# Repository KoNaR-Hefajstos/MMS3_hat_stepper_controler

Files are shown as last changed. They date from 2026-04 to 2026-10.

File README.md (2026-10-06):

# Hat Sterownik silnika krokowego TMC5130A z przetwornicą Buck

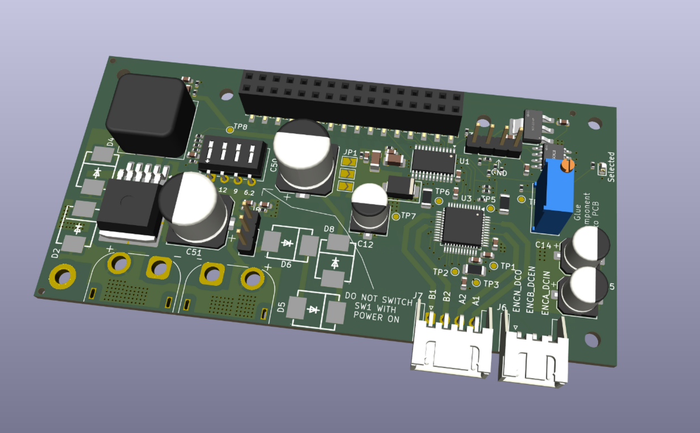
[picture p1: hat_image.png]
zdjecie hata


## Sekcja 1: Dokumentacja Hat'a

### Krótki opis hat'a
Projekt to sterownik silnika krokowego, oparty na dedykowanym układzie scalonym **TMC5130A-TA** sterowanym po SPI. Urządzenie pozwala na sterowanie silnikami o prądzie cewki do 2A (maksymalnie 2.5A w piku). Dodadkowo na PCB jest przetwornica buck oraz złącza i przełączniki do wybierania zasilania, między VIN, 6.2V, 9V, 12V, 24V.

### Zgodność ze standardem ChainBus

* ✅  Używa złącza ChainBus, nie zmienia jego miejsca ani pinoutu.
* ✅  Używa wyłącznie interfejsów I2C, SPI lub UART i nie inicjuje samodzielnie nowych transmisji (Nie jest master'em I2C albo SPI).
* ✅  Spełnia wymagania mechaniczne standardu (wymiary PCB, rozstaw otworów).
* ✅  Pobiera maksymalny prąd zgodny z ilością na jednego hat'a
* ✅  Obsługuje napięcie wejściowe BRD_VIN do wartości 48V.
### Komunikacja i adresowanie

#### Magistrala SPI

| Układ (IC) | Funkcja | Połączenie CS |
| :--- | :--- | :--- |
| **TMC5130A** | Sterownik silnika krokowego | Bezpośrednio do Chainbus'a |

---

### Pinout złączy

#### J6 — Złącze enkodera
Złącze przeznaczone do podłączenia zewnętrznego enkodera zwrotnego.

| Pin | Sygnał | Opis |
| :---- | :--- | :--- |
| **1** | `ENCN_DCO` | |
| **2** | `ENCB_DCEN_CFG4` | |
| **3** | `ENCA_DCIN_CFG5` | |

#### J7 — Złącze silnika krokowego
Złącze wyjściowe do podłączenia faz silnika dwufazowego.

| Pin | Sygnał | Opis |
| :---- | :----- | :--- |
| **1** | `B1` | Faza B (wyjście 1) |
| **2** | `B2` | Faza B (wyjście 2) |
| **3** | `A2` | Faza A (wyjście 2) |
| **4** | `A1` | Faza A (wyjście 1) |

---

### Konfiguracja układu (Zworki/Przełączniki)

#### J8 — Wybór źródła zasilania stopnia mocy silnika
Zworka J8 służy do określenia, skąd sterownik TMC5130A pobiera napięcie zasilania cewek:

| Pozycja zworki  | Wybrane źródło zasilania | Opis |
| :--- | :--- | :--- |
| **Pozycja 1-2** | Przetwornica Buck | Zasilanie silnika z wewnętrznej przetwornicy obniżającej napięcie (napięcie regulowane przełącznikiem SW1). |
| **Pozycja 2-3** | Złącze XT60 (VIN) | Bezpośrednie zasilanie ze złącza XT60. Tor ten posiada trzy szeregowe diody (D5, D6, D7) w celu bezpiecznego dopasowania do maksymalnego zakresu napięć standardu ChainBus. |

#### SW1 — Wybór napięcia wyjściowego przetwornicy Buck
Przełącznik pozwala na wybór napięcia zasilania silnika, jeśli zworka J8 jest ustawiona na zasilanie z przetwornicy.

| Aktywny kanał SW1 | Wyjściowe napięcie | Uwagi |
| :--- | :--- | :--- |
| **Pozycja 1** | 24 V | Domyślne napięcie dla standardowych silników |
| **Pozycja 2** | 12 V | Dla silników średniego napięcia |
| **Pozycja 3** | 9 V | Napięcie zredukowane |
| **Pozycja 4** | 6.2 V | Minimalne stabilne napięcie pracy układu |

* **⚠️ WAŻNE:** Zmianę położenia przełącznika SW1 należy wykonywać wyłącznie przy całkowicie odłączonym zasilaniu modułu. W danym momencie może być włączony tylko jeden przełącznik wyboru napięcia.
* **Modyfikacja poziomów napięć:** Istnieje możliwość zmiany napięc wyjściowych przetwornicy przez zmiane **R14**, **R15** lub **R16**.

#### RV1 — Trymer regulacyjny prądu referencyjnego (AIN_REF)
Potencjometr montażowy RV1 służy do analogowego ustawienia napięcia odniesienia na pinie `AIN_REF` układu TMC5130A, co pozwala na ręczne ograniczenie maksymalnego prądu płynącego przez cewki silnika krokowego.

---

### Szczegółowy opis techniczny
Hat sterownika silnika krokowego używawający TMC5130A-TA. I = 2A

TMC5130A jest sterowana po SPI co umożliwia pełną, programową kontrolę nad wszystkimi parametrami ruchu. Umożliwia to precyzyjną regulację prędkości i pozycji, automatyczne generowanie ramp przyspieszeń i hamowań (co odciąża główny mikrokontroler od obliczeń w czasie rzeczywistym), a także bieżący odczyt diagnostyczny stanu pracy stopnia mocy oraz bezczujnikowe wykrywanie przeciążeń i zablokowania osi.

Opóźniania spowodowane użyciem SPI zamiast standardowego driver'a stepper'a (STEP DIR) poniżej 100us (przesłanie jedner ramki ~= 10us) oraz powoduje mniejsze zajęcie mikrokontrolera (rząda tylko efektu, nie generuje impulsów STEP/DIR)

Przetwornica buck została zaprojektowana tak, aby konwertować napięcie wejściowe na wybrane niższe napięcia robocze silnika. Zaleca się stosowanie zewnętrznego zasilania doprowadzonego do złącza XT60.

### Gotowe arkusze hierarchiczne
W strukturze projektu wykorzystano następujące arkusze hierarchiczne:
* **Buck Regulator** – Układ impulsowej przetwornicy obniżającej napięcie LM2596, wyposażony w przełącznik sprzężenia zwrotnego (SW1) umożliwiający zmianę napięcia wyjściowego (6.2V, 9V, 12V, 24V).
* **Stepper controller** – Schemat  sterownika silnika krokowego TMC5130A-T

---

## Sekcja 2: Specyfikacja standardu ChainBus

### Architektura i łączenie modułów
Standard ChainBus umożliwia modułowe łączenie hatów. Na jednym MMS3 można zamontować pionowo **do 8 hat'ów**. Połączenie realizowane jest poprzez wpięcie złącza męskiego kolejnego hat'a w złącze żeńskie poprzedniego.

### Komunikacja i sterowanie
Magistrala ChainBus jest w pełni cyfrowa. Płyta główna nie steruje bezpośrednio sygnałami ogólnego przeznaczenia (GPIO) na poszczególnych hat'ach. Wszelkie operacje muszą być realizowane przez dedykowane układy scalone komunikujące się przez interfejsy systemowe.

Wybór aktywnego modułu realizowany jest przez układ przełącznika magistrali (bus switch) na płycie głównej. Dzięki temu linie I2C, SPI i UART są niezależne dla każdego hat'a (brak konfliktów adresów I2C oraz kolizji na liniach SPI CS).
* **Identyfikacja:** Każdy moduł powinien posiadać pamięć EEPROM na magistrali I2C w celu identyfikacji płyty przez system - układ M24C64-W skonfigurowany na adres `1010000` przy liniach adresowych A0, A1, A2 zwartych do masy.

### Zasilanie
Złącze ChainBus dostarcza następujące linie zasilania:

| Magistrala zasilania | Napięcie znamionowe | Maksymalny prąd (łączny dla 8 hatów) | Szacowany prąd na jeden hat |
| :--- | :---: | :---: | :---: |
| **5V** | 5.0 V | 1.0 A | 125 mA |
| **12V stby** | 12.0 V | 0.5 A | 65 mA |
| **BRD_VIN** | 12.0 V – 48.0 V | 1.5 A | 185 mA |

*   Komponenty podłączone do linii `BRD_VIN` muszą być przystosowane do pracy z napięciem od 12V do **48 V**.
*   W przypadku dużego zapotrzebowania na prąd (np. jednoczesna praca kilku silników o wysokim momencie obrotowym), dopuszczalne jest skorzystanie z dedykowanego wysokoprądowego złącza XT60.

### Wymagania mechaniczne i złącza
* **Wymiary PCB:** Niedozwolona jest zmiana obrysu płytki oraz położenia otworów montażowych, aby zachować kompatybilność mechaniczną.
* **Pozycjonowanie złączy ChainBus:** Położenie złącza standardu 2x16 SMD (raster 2.54 mm) musi być zgodne z szablonem. Złącze żeńskie montowane jest na stronie FRONT, natomiast złącze męskie na stronie BACK.
* **Komponenty:** Wszystkie komponenty powinny znajdować się na stronie FRONT płytki, aby uniknąć kolizji mechanicznych z elementami sąsiadujących modułów w stosie.

---

## Sekcja 3: Licencja, linki i tagi

### Licencjonowanie projektu

*   **PCB:** [CERN-OHL-W](https://ohwr.org/project/cernohl/wikis/Documents/CERN-OHL-version-2) - Umożliwia modyfikacje i sprzedaż, ale wymaga zachowania informacji o autorze, a wszelkie pochodne projekty muszą być udostępnione jako open source.
*   **Software:** [MIT License](https://opensource.org/licenses/MIT) - Umożliwia dowolne modyfikacje i sprzedaż komercyjną pod warunkiem dołączenia informacji o autorze (kod wynikowy nie musi być udostępniany jako open source).

### Tagi projektu
#chainbus #MMS3 #ModuCard #StepperDriver #TMC5130A #BuckConverter

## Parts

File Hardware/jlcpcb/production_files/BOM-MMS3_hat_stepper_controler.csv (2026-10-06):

Comment | Designator | Footprint | LCSC | Quantity
0603/3R3 | R4 | R_1206 | C911994 | 1
100kΩ | R5 | R_0402 | C25741 | 1
100nF | C1,C2,C20,C21,C23,C24,C3,C7,C8,C9 | C_0603 | C14663 | 10
100uF | C50,C51 | CP_Elec_10x10 | C249838 | 2
100uH 4A | L1 | L_Sunlord_SWRB1207S | C5368704 | 1
10kΩ | R1,R19,R2,R20,R21,R22,R23,R24,R25 | R_0402 | C25744 | 9
10uF | C16,C18 | C_0603 | C19702 | 2
1206, 0R15, 0.5W | R6,R7 | R_1206 | C2683383 | 2
18.7k | R13 | R_0402 | C11476 | 1
1kΩ | R12 | R_0402 | C11702 | 1
22nF | C5 | C_0603 | C21122 | 1
3.3nF | C22 | C_0603 | C1613 | 1
330Ω | R26 | R_0402 | C25104 | 1
33kΩ | R10,R11,R17,R18,R8,R9 | R_0402 | C25779 | 6
4.7uF | C4 | C_0603 | C19666 | 1
4.7uF | C10,C11 | C_1206 | C29823 | 2
470nF | C6 | C_0603 | C1623 | 1
47u | C12,C14,C15 | CP_Elec_6.3x7.7 | C7461235 | 3
5.11k | R16 | R_0402 | C274895 | 1
9.53k | R15 | R_0402 | C295883 | 1
AMS1117 | U4 | SOT-223-3_L6.5-W3.4-P2.30-LS7.0-BR | C6186 | 1
LM2596HVS-ADJRG | U5 | TO-263-5_TabPin3 | C22439312 | 1
M24C64 | U2 | SOIC-8_L5.0-W4.0-P1.27-LS6.0-BL | C79988 | 1
Red | D7 | D_0603 | C2286 | 1
SN74CB3Q3384APW | U1 | TSSOP-24_4.4x7.8mm_P0.65mm | C469874 | 1
SS510C | D2,D4,D5,D6,D8 | SMC_L7.1-W6.2-LS8.1-RD | C123944 | 5
SW_DIP_x04 | SW1 | SW_DIP_SPSTx04_Slide_6.7x11.72mm_W7.62mm_P2.54mm_LowProfile | C231756 | 1
TMC5130A-TA | U3 | TQFP-48-1EP_7x7mm_P0.5mm_EP5x5mm_ThermalVias | C188832 | 1
TestPoint | TP4 | TestPoint_Pad_D1.0mm |  | 1
TestPoint | TP1 | TestPoint_Pad_D1.0mm |  | 1
16.5k | R14 | R_0402 |  | 1
TestPoint | TP7 | TestPoint_Pad_D1.0mm |  | 1
TestPoint | TP6 | TestPoint_Pad_D1.0mm |  | 1
TestPoint | TP8 | TestPoint_Pad_D1.0mm |  | 1
TestPoint | TP5 | TestPoint_Pad_D1.0mm |  | 1
100K TRIM | RV1 | Potentiometer_Bourns_3296W_Vertical |  | 1
TestPoint | TP2 | TestPoint_Pad_D1.0mm |  | 1
TestPoint | TP3 | TestPoint_Pad_D1.0mm |  | 1

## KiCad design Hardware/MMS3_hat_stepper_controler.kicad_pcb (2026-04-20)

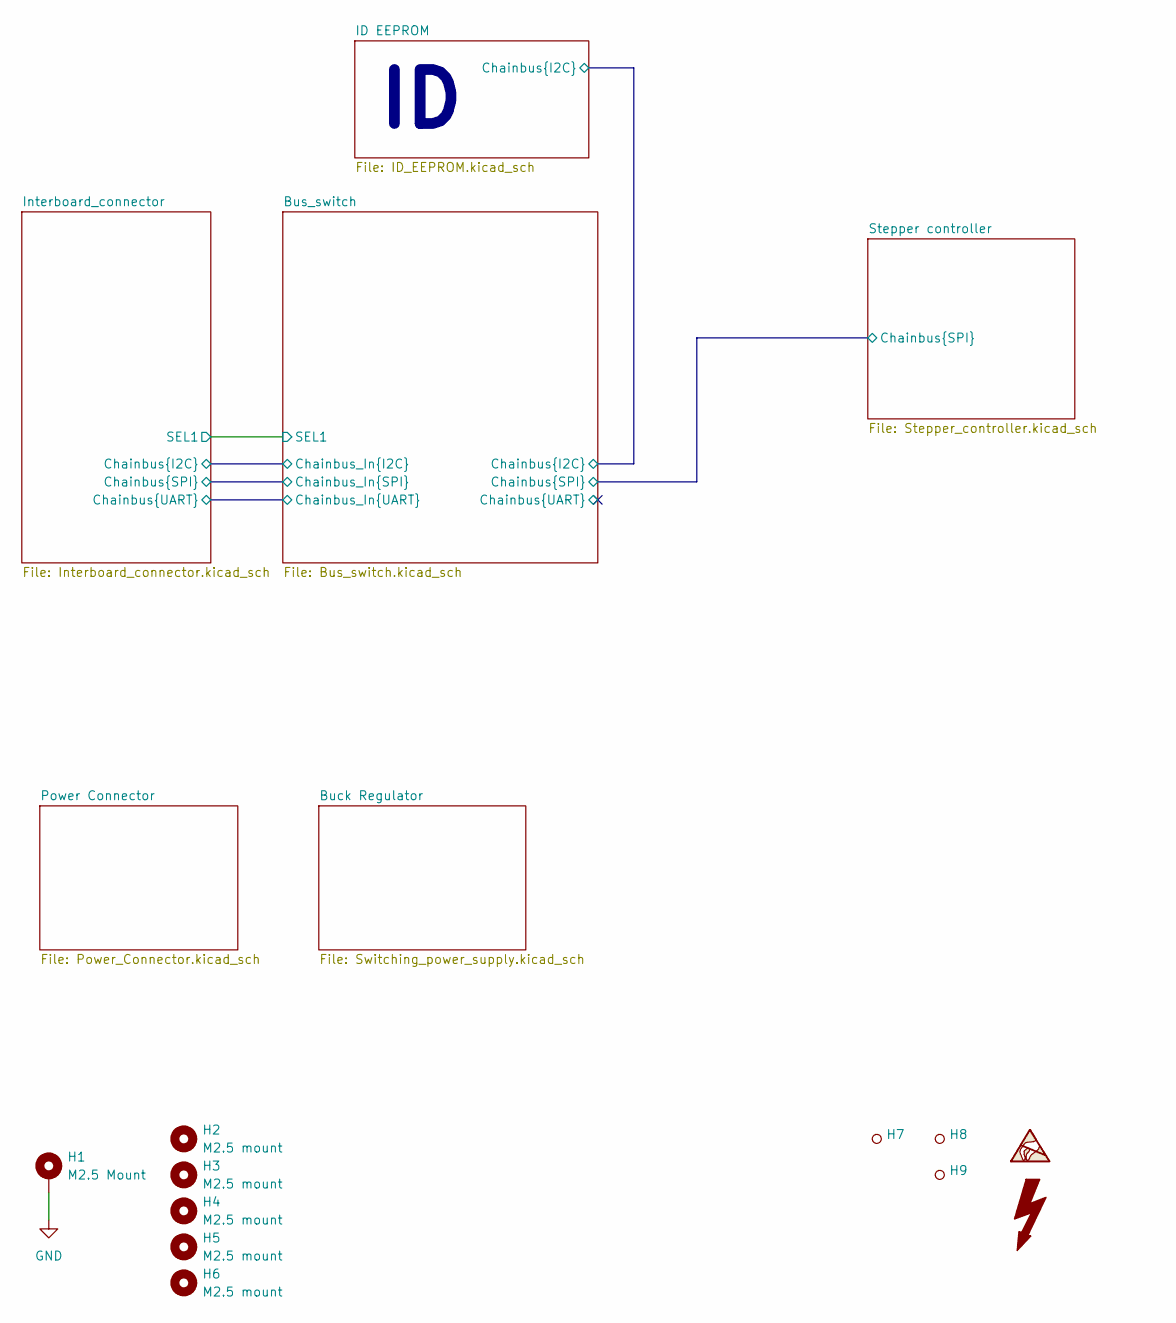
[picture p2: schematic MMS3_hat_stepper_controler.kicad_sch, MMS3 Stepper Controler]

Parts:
H1: M2.5 Mount; MountingHole_2.7mm_M2.5_DIN965_Pad_TopOnly
H2, H3, H4, H5, H6: M2.5 mount; MountingHole_2.7mm_M2.5
H7, H8, H9: Hole_Tooling_JLCPCB

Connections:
GND: H1.1 (1_1); also elsewhere on the board

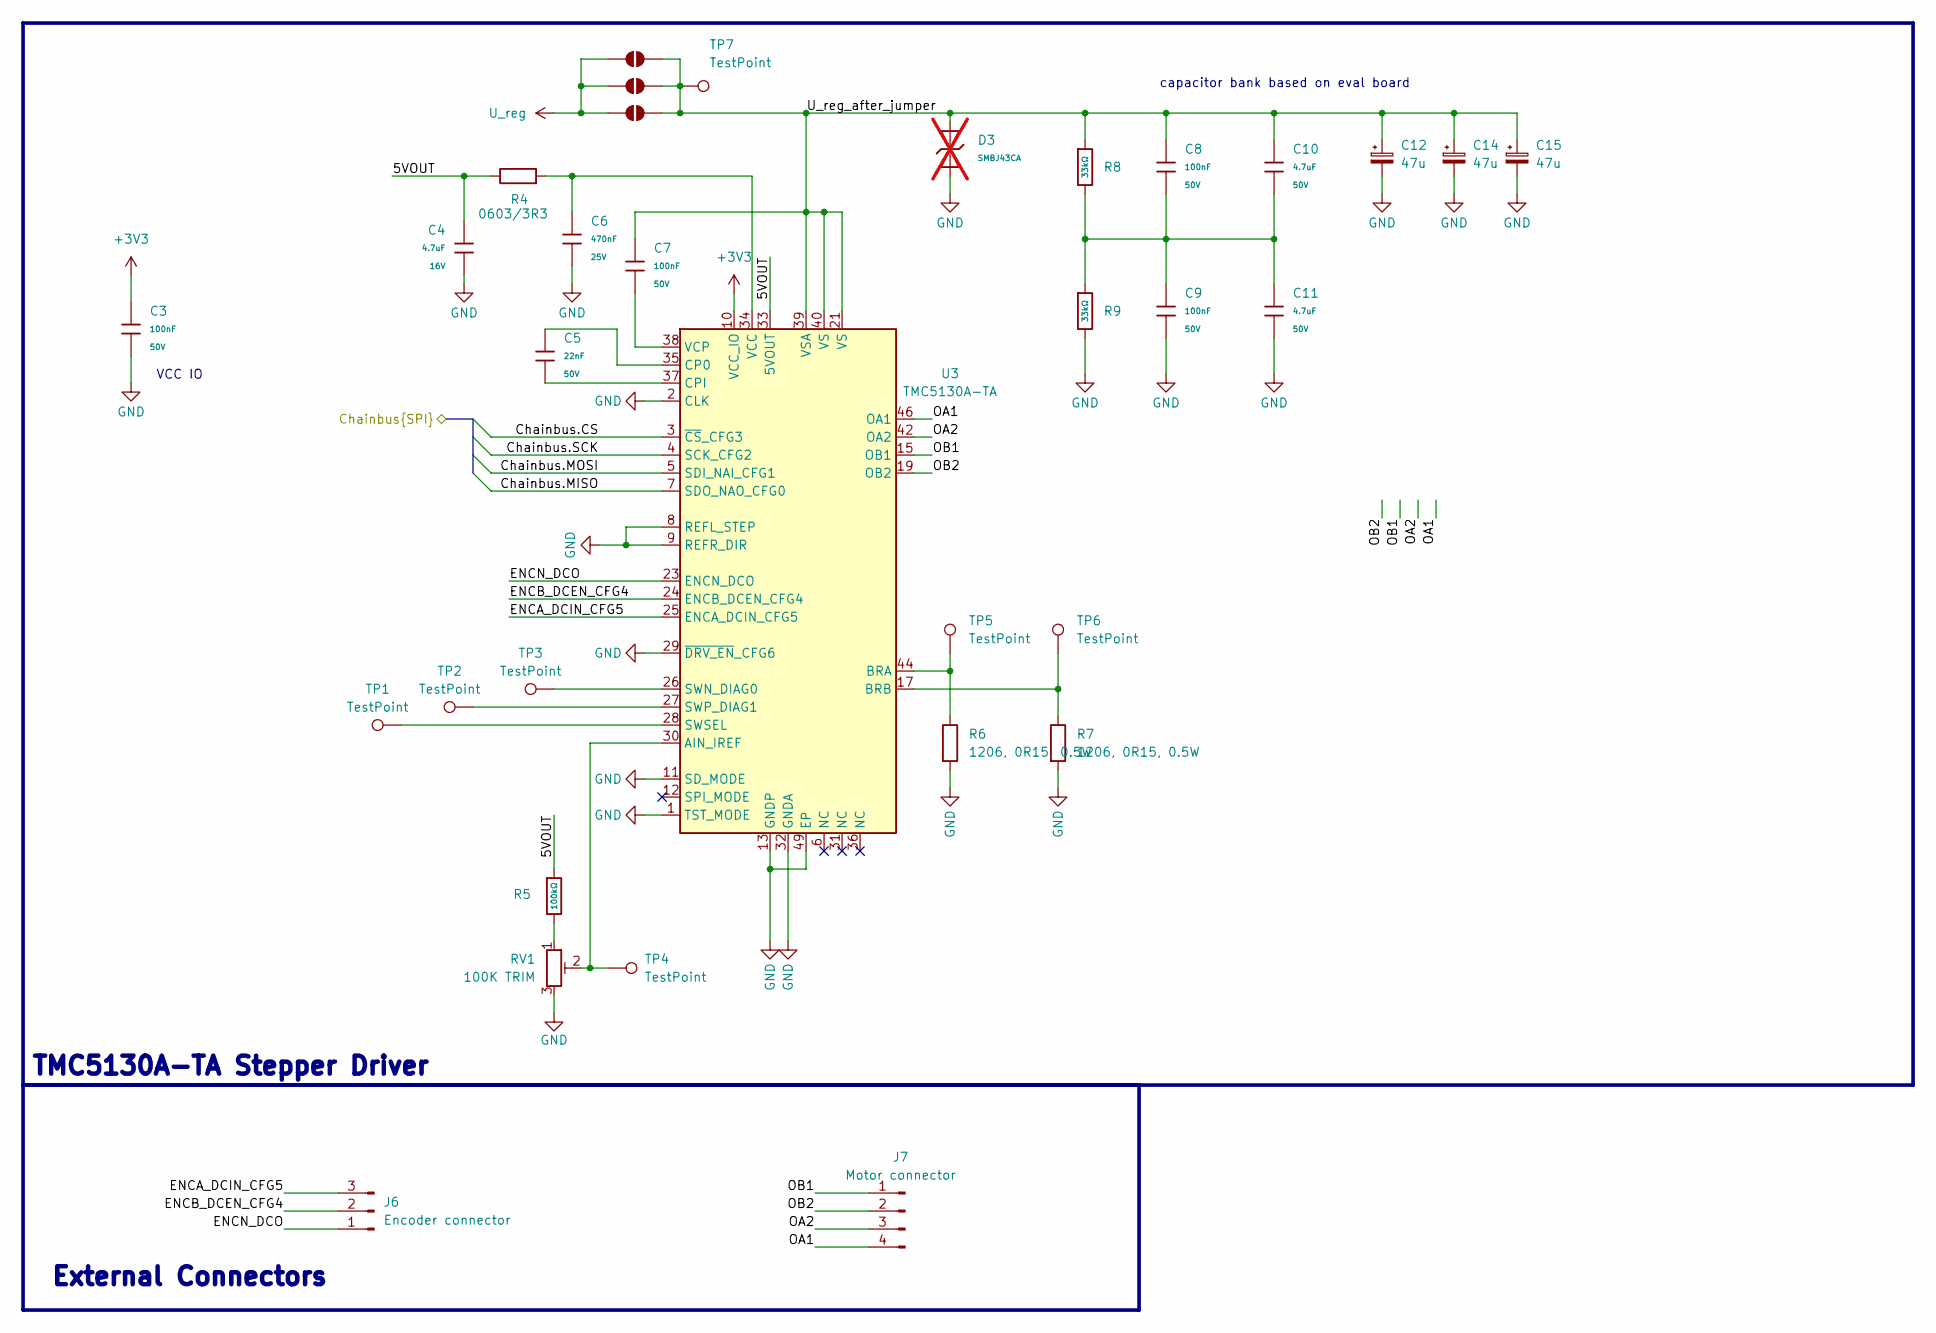
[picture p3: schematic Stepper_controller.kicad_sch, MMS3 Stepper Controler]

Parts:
C3, C7, C8, C9: 100nF; C_0603; Voltage Rated 50V; Tolerance ±10%; Part CC0603KRX7R9BB104; LCSC C14663
C4: 4.7uF; C_0603; Voltage Rated 16V; Tolerance ±10%; Part CL10A475KO8NNNC; LCSC C19666
C5: 22nF; C_0603; Voltage Rated 50V; Tolerance ±10%; Part CL10B223KB8NNNC; LCSC C21122
C6: 470nF; C_0603; Voltage Rated 25V; Tolerance ±10%; Part CL10B474KA8NNNC; LCSC C1623
C10, C11: 4.7uF; C_1206; Voltage Rated 50V; Tolerance ±10%; Part 1206B475K500NT; LCSC C29823
C12, C14, C15: 47u; CP_Elec_6.3x7.7; LCSC C7461235
D3: SMBJ43CA; D_SMB; Breakdown Voltage 52.8V; Part SMBJ43CA; LCSC C41376098; not fitted
J6: Encoder connector; JST_XH_S3B-XH-A-1_1x03_P2.50mm_Horizontal
J7: Motor connector; JST_XH_S4B-XH-A_1x04_P2.50mm_Horizontal
JP1, JP2, JP3: SolderJumper_2_Open; SolderJumper-2_P1.3mm_Open_TrianglePad1.0x1.5mm
R4: 0603/3R3; R_1206; LCSC C911994
R5: 100kΩ; R_0402; Overload Voltage (Max) 50V; Tolerance ±1%; Part 0402WGF1003TCE; LCSC C25741
R6, R7: 1206, 0R15, 0.5W; R_1206; LCSC C2683383
R8, R9: 33kΩ; R_0402; Overload Voltage (Max) 50V; Tolerance ±1%; Part 0402WGF3302TCE; LCSC C25779
RV1: 100K TRIM; Potentiometer_Bourns_3296W_Vertical; LCSC C48641782
TP1, TP2, TP3, TP4, TP5, TP6, TP7: TestPoint; TestPoint_Pad_D1.0mm
U3: TMC5130A-TA; TQFP-48-1EP_7x7mm_P0.5mm_EP5x5mm_ThermalVias; LCSC C188832

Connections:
+3V3: C3.1, U3.10 (VCC_IO); also elsewhere on the board
/Bus_switch/Chainbus.CS: U3.3 (~CS_CFG3); also elsewhere on the board
/Bus_switch/Chainbus.MISO: U3.7 (SDO_NAO_CFG0); also elsewhere on the board
/Bus_switch/Chainbus.MOSI: U3.5 (SDI_NAI_CFG1); also elsewhere on the board
/Bus_switch/Chainbus.SCK: U3.4 (SCK_CFG2); also elsewhere on the board
/Stepper controller/5VOUT: C4.1, R4.1, R5.1, U3.33 (5VOUT)
/Stepper controller/ENCA_DCIN_CFG5: J6.3, U3.25 (ENCA_DCIN_CFG5)
/Stepper controller/ENCB_DCEN_CFG4: J6.2, U3.24 (ENCB_DCEN_CFG4)
/Stepper controller/ENCN_DCO: J6.1, U3.23 (ENCN_DCO)
/Stepper controller/OA1: J7.4, U3.46 (OA1)
/Stepper controller/OA2: J7.3, U3.42 (OA2)
/Stepper controller/OB1: J7.1, U3.15 (OB1)
/Stepper controller/OB2: J7.2, U3.19 (OB2)
/Stepper controller/U_reg_after_jumper: C7.1, C8.1, C10.1, C12.1, C14.1, C15.1, D3.2, JP1.2 (B), JP2.2 (B), JP3.2 (B), R8.1, TP7.1 (1_1), U3.21 (VS), U3.39 (VSA), U3.40 (VS)
GND: C3.2, C4.2, C6.2, C9.2, C11.2, C12.2, C14.2, C15.2, D3.1, R6.2, R7.2, R9.2, RV1.3, U3.1 (TST_MODE), U3.2 (CLK), U3.8 (REFL_STEP), U3.9 (REFR_DIR), U3.11 (SD_MODE), U3.13 (GNDP), U3.29 (~DRV_EN_CFG6), U3.32 (GNDA), U3.48 (GNDP), U3.49 (EP); also elsewhere on the board
unnamed: C8.2, C9.1, C10.2, C11.1, R8.2, R9.1
unnamed: R5.2, RV1.1
unnamed: RV1.2, TP4.1 (1_1), U3.30 (AIN_IREF)
unnamed: R6.1, TP5.1 (1_1), U3.44 (BRA)
unnamed: R7.1, TP6.1 (1_1), U3.17 (BRB)
unnamed: C5.1, U3.35 (CP0)
unnamed: C5.2, U3.37 (CPI)
unnamed: TP3.1 (1_1), U3.26 (SWN_DIAG0)
unnamed: TP2.1 (1_1), U3.27 (SWP_DIAG1)
unnamed: TP1.1 (1_1), U3.28 (SWSEL)
unnamed: C6.1, R4.2, U3.34 (VCC)
unnamed: C7.2, U3.38 (VCP)
U_reg: JP1.1 (A), JP2.1 (A), JP3.1 (A); also elsewhere on the board

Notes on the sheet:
VCC IO
TMC5130A-TA Stepper Driver
External Connectors
capacitor bank based on eval board

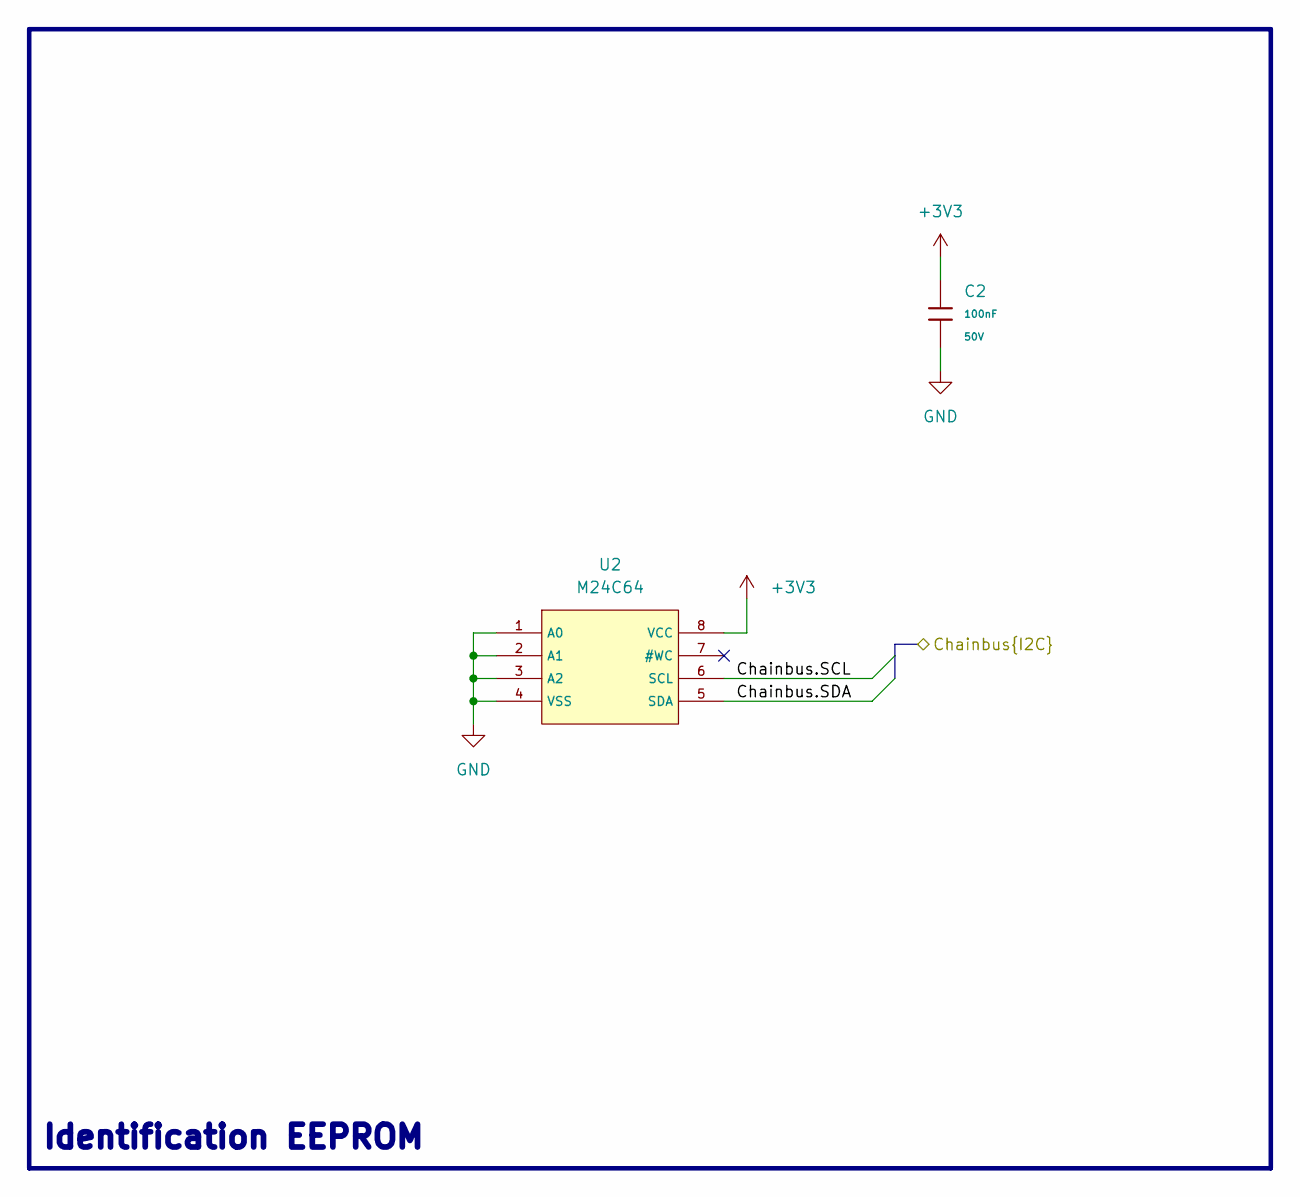
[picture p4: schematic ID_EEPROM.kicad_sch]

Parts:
C2: 100nF; C_0603; Voltage Rated 50V; Tolerance ±10%; Part CC0603KRX7R9BB104; LCSC C14663
U2: M24C64; SOIC-8_L5.0-W4.0-P1.27-LS6.0-BL; Supply Voltage 1.8V~5.5V; Part M24C64-RMN6TP; LCSC C79988

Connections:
+3V3: C2.1, U2.8 (VCC); also elsewhere on the board
/Bus_switch/Chainbus.SCL: U2.6 (SCL); also elsewhere on the board
/Bus_switch/Chainbus.SDA: U2.5 (SDA); also elsewhere on the board
GND: C2.2, U2.1 (A0), U2.2 (A1), U2.3 (A2), U2.4 (VSS); also elsewhere on the board

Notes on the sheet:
Identification EEPROM

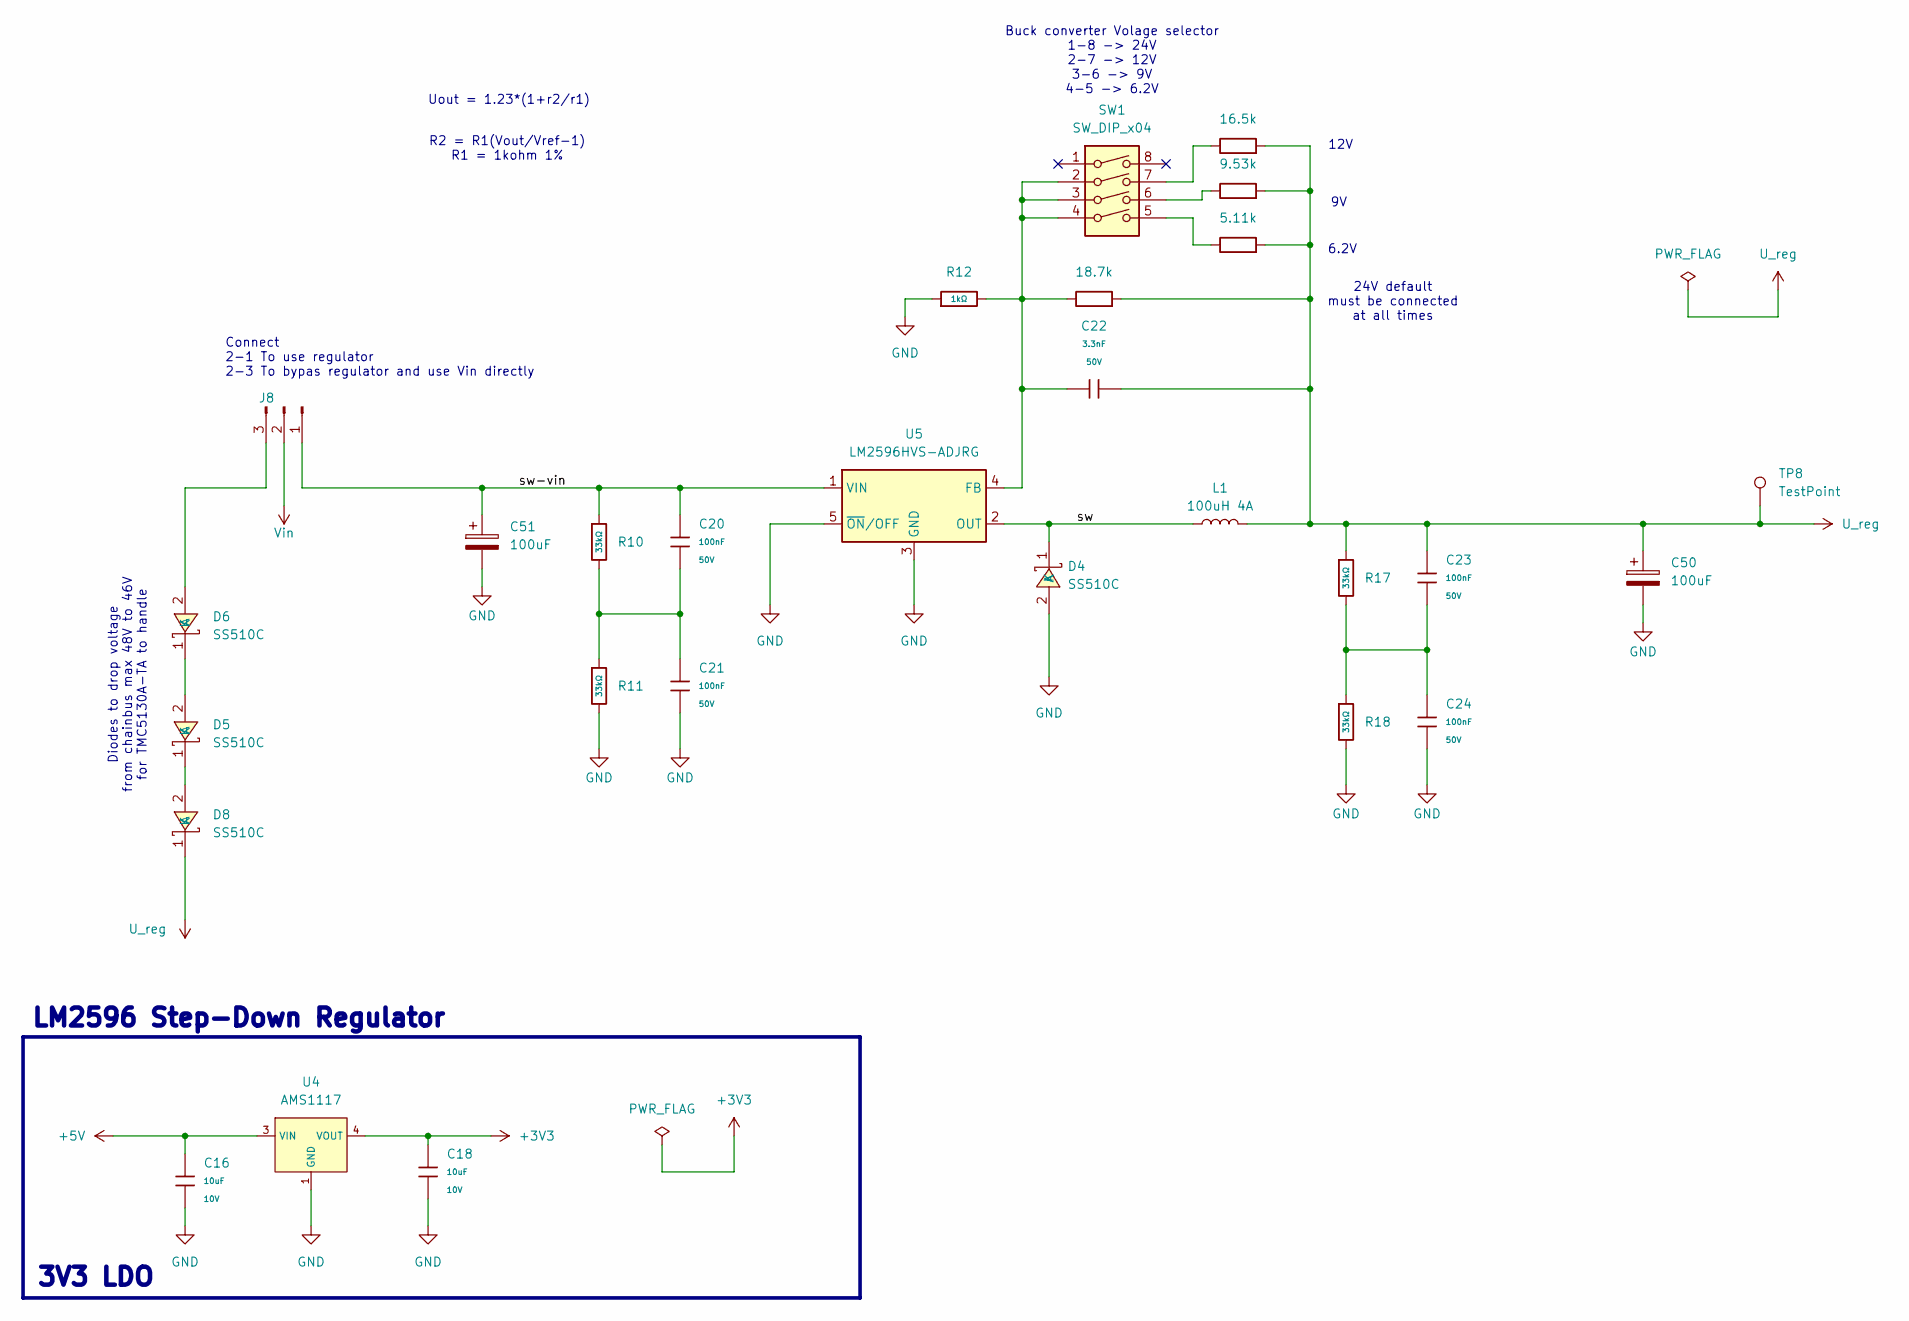
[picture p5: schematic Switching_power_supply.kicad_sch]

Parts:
C16, C18: 10uF; C_0603; Voltage Rated 10V; Tolerance ±10%; Part CL10A106KP8NNNC; LCSC C19702
C20, C21, C23, C24: 100nF; C_0603; Voltage Rated 50V; Tolerance ±10%; Part CC0603KRX7R9BB104; LCSC C14663
C22: 3.3nF; C_0603; Voltage Rated 50V; Tolerance ±10%; Part CL10B332KB8NNNC; LCSC C1613
C50, C51: 100uF; CP_Elec_10x10; MPN VZH101M1KTR-1010; LCSC C249838
D4, D5, D6, D8: SS510C; SMC_L7.1-W6.2-LS8.1-RD; MPN SS510C; LCSC Part C123944
J8: Conn_01x03_Pin; PinHeader_1x03_P2.54mm_Vertical
L1: 100uH 4A; L_Sunlord_SWRB1207S; LCSC C5368704
R10, R11, R17, R18: 33kΩ; R_0402; Overload Voltage (Max) 50V; Tolerance ±1%; Part 0402WGF3302TCE; LCSC C25779
R12: 1kΩ; R_0402; Overload Voltage (Max) 50V; Tolerance ±1%; Part 0402WGF1001TCE; LCSC C11702
R13: 18.7k; R_0402; LCSC C11476
R14: 16.5k; R_0402; LCSC C25857
R15: 9.53k; R_0402; LCSC C295883
R16: 5.11k; R_0402; LCSC C274895
SW1: SW_DIP_x04; SW_DIP_SPSTx04_Slide_6.7x11.72mm_W7.62mm_P2.54mm_LowProfile; LCSC C231756
TP8: TestPoint; TestPoint_Pad_D1.0mm
U4: AMS1117; SOT-223-3_L6.5-W3.4-P2.30-LS7.0-BR; Output Voltage 3.3V; Dropout Voltage 1.3V@(800mA); Part AMS1117-3.3; LCSC C6186
U5: LM2596HVS-ADJRG; TO-263-5_TabPin3; LCSC C22439312

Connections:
+3V3: C18.1, U4.2 (VOUT), U4.4 (VOUT); also elsewhere on the board
+5V: C16.1, U4.3 (VIN); also elsewhere on the board
/Buck Regulator/sw: D4.1 (K), L1.1, U5.2 (OUT)
/Buck Regulator/sw-vin: C20.1, C51.1, J8.1, R10.1, U5.1 (VIN)
GND: C16.2, C18.2, C21.2, C24.2, C50.2, C51.2, D4.2 (A), R11.2, R12.1, R18.2, U4.1 (GND), U5.3 (GND), U5.5 (~ON/OFF); also elsewhere on the board
unnamed: C20.2, C21.1, R10.2, R11.1
unnamed: C23.2, C24.1, R17.2, R18.1
unnamed: D5.2 (A), D6.1 (K)
unnamed: D5.1 (K), D8.2 (A)
unnamed: D6.2 (A), J8.3
unnamed: R14.1, SW1.7
unnamed: R15.1, SW1.6
unnamed: R16.1, SW1.5
unnamed: C22.1, R12.2, R13.1, SW1.2, SW1.3, SW1.4, U5.4 (FB)
U_reg: C22.2, C23.1, C50.1, D8.1 (K), L1.2, R13.2, R14.2, R15.2, R16.2, R17.1, TP8.1 (1_1); also elsewhere on the board
Vin: J8.2; also elsewhere on the board

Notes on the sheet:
6.2V
Diodes to drop voltage from chainbus max 48V to 46V for TMC5130A-TA to handle
3V3 LDO
R2 = R1(Vout/Vref-1) R1 = 1kohm 1%
LM2596 Step-Down Regulator
Uout = 1.23*(1+r2/r1)
Buck converter Volage selector 1-8 -> 24V 2-7 -> 12V 3-6 -> 9V 4-5 -> 6.2V
Connect 2-1 To use regulator 2-3 To bypas regulator and use Vin directly
12V
24V default must be connected at all times

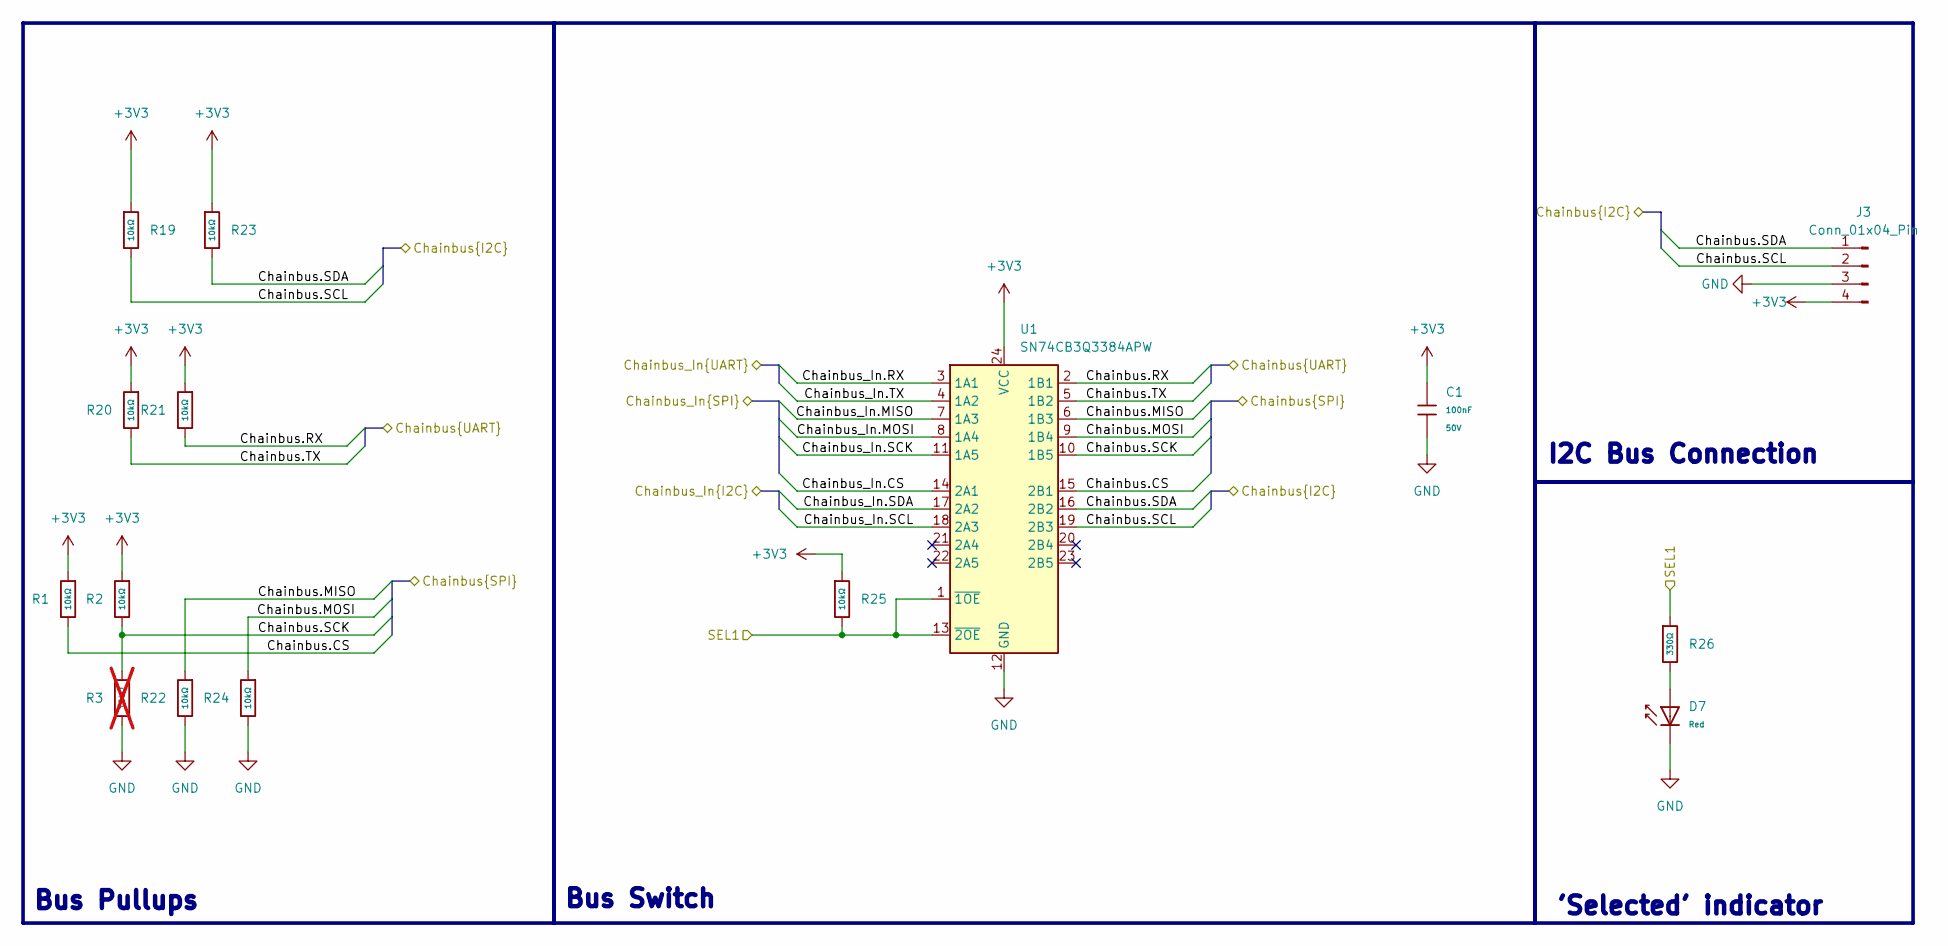
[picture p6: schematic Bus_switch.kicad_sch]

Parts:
C1: 100nF; C_0603; Voltage Rated 50V; Tolerance ±10%; Part CC0603KRX7R9BB104; LCSC C14663
D7: Red; D_0603; Part KT-0603R; LCSC C2286
J3: Conn_01x04_Pin; PinHeader_1x04_P2.54mm_Vertical
R1, R2, R19, R20, R21, R22, R23, R24, R25: 10kΩ; R_0402; Overload Voltage (Max) 50V; Tolerance ±1%; Part 0402WGF1002TCE; LCSC C25744
R3: 10kΩ; R_0402; Overload Voltage (Max) 50V; Tolerance ±1%; Part 0402WGF1002TCE; LCSC C25744; not fitted
R26: 330Ω; R_0402; Overload Voltage (Max) 50V; Tolerance ±1%; Part 0402WGF3300TCE; LCSC C25104
U1: SN74CB3Q3384APW; TSSOP-24_4.4x7.8mm_P0.65mm; LCSC C469874

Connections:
+3V3: C1.1, J3.4, R1.1, R2.1, R19.1, R20.1, R21.1, R23.1, R25.1, U1.24 (VCC); also elsewhere on the board
/Bus_switch/Chainbus.CS: R1.2, U1.15 (2B1); also elsewhere on the board
/Bus_switch/Chainbus.MISO: R22.1, U1.6 (1B3); also elsewhere on the board
/Bus_switch/Chainbus.MOSI: R24.1, U1.9 (1B4); also elsewhere on the board
/Bus_switch/Chainbus.RX: R21.2, U1.2 (1B1)
/Bus_switch/Chainbus.SCK: R2.2, R3.1, U1.10 (1B5); also elsewhere on the board
/Bus_switch/Chainbus.SCL: J3.2, R19.2, U1.19 (2B3); also elsewhere on the board
/Bus_switch/Chainbus.SDA: J3.1, R23.2, U1.16 (2B2); also elsewhere on the board
/Bus_switch/Chainbus.TX: R20.2, U1.5 (1B2)
/Bus_switch/Chainbus_In.CS: U1.14 (2A1); also elsewhere on the board
/Bus_switch/Chainbus_In.MISO: U1.7 (1A3); also elsewhere on the board
/Bus_switch/Chainbus_In.MOSI: U1.8 (1A4); also elsewhere on the board
/Bus_switch/Chainbus_In.RX: U1.3 (1A1); also elsewhere on the board
/Bus_switch/Chainbus_In.SCK: U1.11 (1A5); also elsewhere on the board
/Bus_switch/Chainbus_In.SCL: U1.18 (2A3); also elsewhere on the board
/Bus_switch/Chainbus_In.SDA: U1.17 (2A2); also elsewhere on the board
/Bus_switch/Chainbus_In.TX: U1.4 (1A2); also elsewhere on the board
/Bus_switch/SEL1: R25.2, R26.1, U1.1 (~1OE), U1.13 (~2OE); also elsewhere on the board
GND: C1.2, D7.1, J3.3, R3.2, R22.2, R24.2, U1.12 (GND); also elsewhere on the board
unnamed: D7.2, R26.2

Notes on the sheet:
Bus Switch
Bus Pullups
'Selected' indicator
I2C Bus Connection

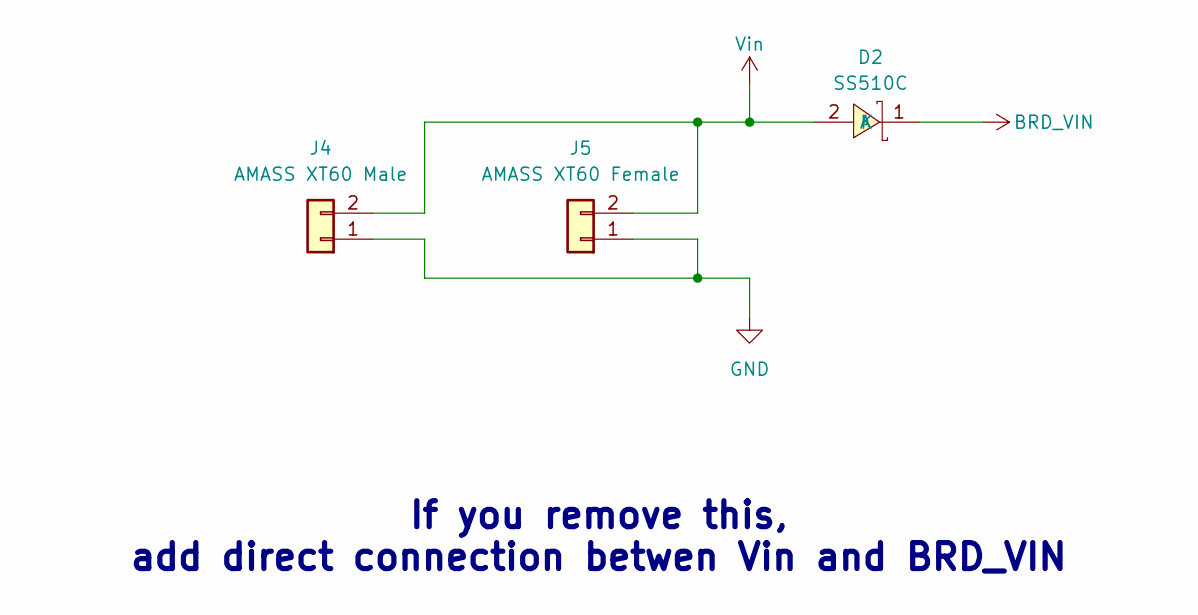
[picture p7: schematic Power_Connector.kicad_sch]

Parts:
D2: SS510C; SMC_L7.1-W6.2-LS8.1-RD; MPN SS510C; LCSC Part C123944
J4: AMASS XT60 Male; AMASS_XT60PW-M_1x02_P7.20mm_Horizontal; LCSC C98732
J5: AMASS XT60 Female; AMASS_XT60PW-F_1x02_P7.20mm_Horizontal; LCSC C428722

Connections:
BRD_VIN: D2.1 (K); also elsewhere on the board
GND: J4.1, J5.1; also elsewhere on the board
Vin: D2.2 (A), J4.2, J5.2; also elsewhere on the board

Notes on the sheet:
If you remove this, add direct connection betwen Vin and BRD_VIN

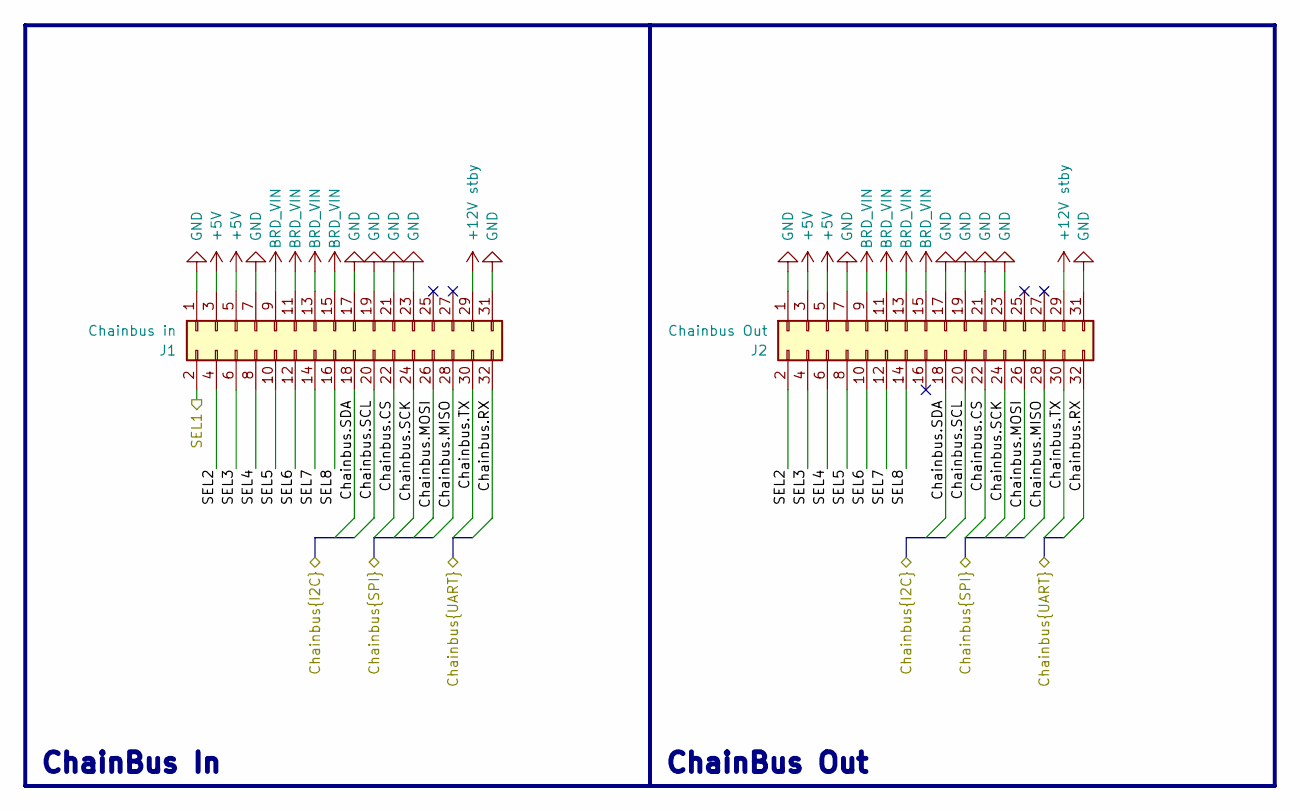
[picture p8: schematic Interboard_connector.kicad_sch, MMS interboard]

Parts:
J1: Chainbus in; PinHeader_2x16_P2.54mm_Vertical_SMD
J2: Chainbus Out; PinSocket_2x16_P2.54mm_Vertical_SMD

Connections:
+5V: J1.3, J1.5, J2.3, J2.5; also elsewhere on the board
+12V stby: J1.29, J2.29
/Bus_switch/Chainbus_In.CS: J1.22, J2.22; also elsewhere on the board
/Bus_switch/Chainbus_In.MISO: J1.28, J2.28; also elsewhere on the board
/Bus_switch/Chainbus_In.MOSI: J1.26, J2.26; also elsewhere on the board
/Bus_switch/Chainbus_In.RX: J1.32, J2.32; also elsewhere on the board
/Bus_switch/Chainbus_In.SCK: J1.24, J2.24; also elsewhere on the board
/Bus_switch/Chainbus_In.SCL: J1.20, J2.20; also elsewhere on the board
/Bus_switch/Chainbus_In.SDA: J1.18, J2.18; also elsewhere on the board
/Bus_switch/Chainbus_In.TX: J1.30, J2.30; also elsewhere on the board
/Bus_switch/SEL1: J1.2; also elsewhere on the board
/Interboard_connector/SEL2: J1.4, J2.2
/Interboard_connector/SEL3: J1.6, J2.4
/Interboard_connector/SEL4: J1.8, J2.6
/Interboard_connector/SEL5: J1.10, J2.8
/Interboard_connector/SEL6: J1.12, J2.10
/Interboard_connector/SEL7: J1.14, J2.12
/Interboard_connector/SEL8: J1.16, J2.14
BRD_VIN: J1.9, J1.11, J1.13, J1.15, J2.9, J2.11, J2.13, J2.15; also elsewhere on the board
GND: J1.1, J1.7, J1.17, J1.19, J1.21, J1.23, J1.31, J2.1, J2.7, J2.17, J2.19, J2.21, J2.23, J2.31; also elsewhere on the board

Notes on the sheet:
ChainBus In
ChainBus Out

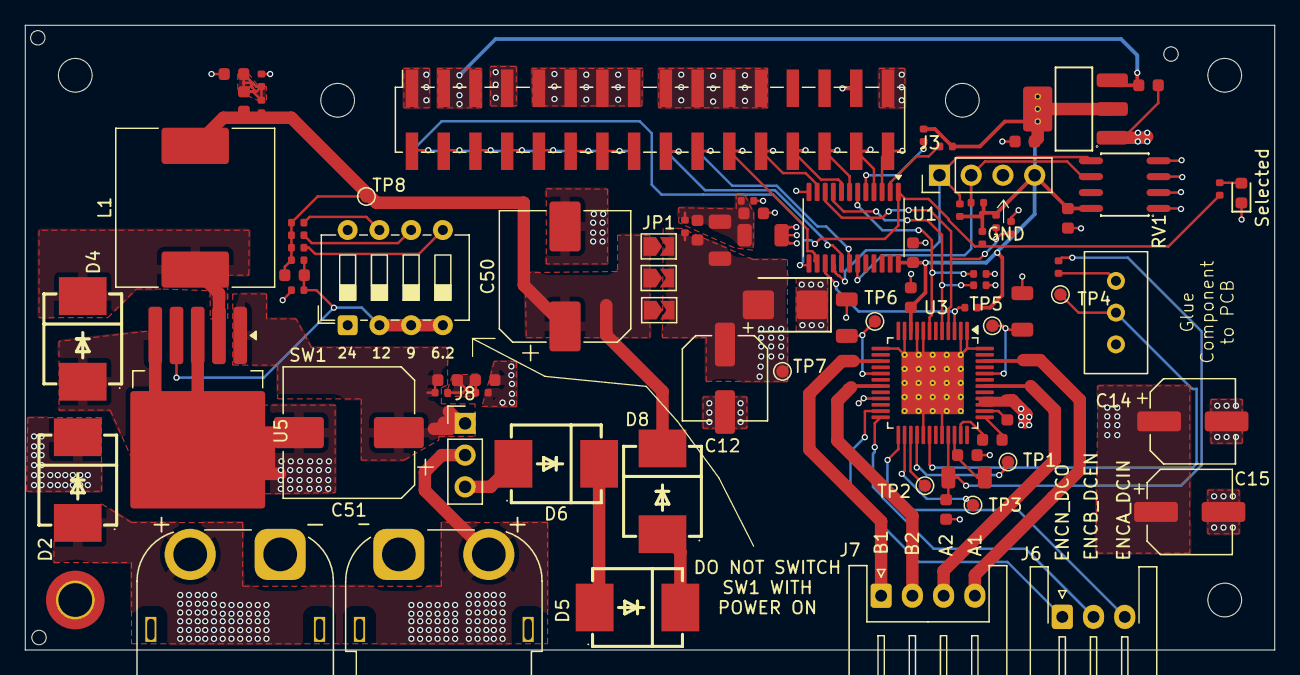
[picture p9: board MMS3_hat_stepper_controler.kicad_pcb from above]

Board: 4 copper layers, 100.0 x 50.0 mm, 92 parts (1 on the bottom side), 64 nets.

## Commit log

2026-01-28 finished schematic (without some part numbers)
    [Bus_switch.kicad_sch, ID_EEPROM.kicad_sch, Interboard_connector.kicad_sch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]
2026-02-06 initial component placement
    [Bus_switch.kicad_sch, MMS3_hat_stepper_controler.kicad_pcb, Power_Connector.kicad_sch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]
2026-02-07 added PCB from mechanical template
    [MMS3_hat_stepper_controler.kicad_pcb]
2026-02-08 second component placement
    [Bus_switch.kicad_sch, ID_EEPROM.kicad_sch, Interboard_connector.kicad_sch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]
2026-02-10 Added design rules to PCB and updated dip switch
    [MMS3_hat_stepper_controler.kicad_pcb, Power_Connector.kicad_sch, Stepper_controller.kicad_sch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]
2026-02-17 Added Routing
    [Bus_switch.kicad_sch, MMS3_hat_stepper_controler.kicad_pcb, Stepper_controller.kicad_sch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]
2026-02-24 updated routing
    [Bus_switch.kicad_sch, MMS3_hat_stepper_controler.kicad_pcb, Stepper_controller.kicad_sch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]
2026-02-27 minor fixes + production files
    [BOM-MMS3_hat_stepper_controler.csv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]
2026-02-28 added pullup on select
    [BOM-MMS3_hat_stepper_controler.csv, Bus_switch.kicad_sch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]
2026-04-08 added pinout on silkscreen
    [BOM-MMS3_hat_stepper_controler.csv, Bus_switch.kicad_sch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]
2026-04-08 added clearance for mounting
    [BOM-MMS3_hat_stepper_controler.csv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]
2026-04-08 added rounded corners :)
    [MMS3_hat_stepper_controler.kicad_pcb]
2026-04-08 generated production files
    [CPL-MMS3_hat_stepper_controler.csv, MMS3_hat_stepper_controler-CuBottom.gbr, MMS3_hat_stepper_controler-CuIn1.gbr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]
2026-04-08 added version number
    [MMS3_hat_stepper_controler-CuBottom.gbr, MMS3_hat_stepper_controler-CuIn1.gbr, MMS3_hat_stepper_controler-CuIn2.gbr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]
2026-04-11 changed diode to JLCMANUFACTURING
    [Bus_switch.kicad_sch, MMS3_hat_stepper_controler.kicad_pcb]
2026-04-11 moved XT60
    [MMS3_hat_stepper_controler.kicad_pcb]
2026-04-11 generated gerber
    [BOM-MMS3_hat_stepper_controler.csv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]
2026-04-11 ... I forgot to move the converter.
    [BOM-MMS3_hat_stepper_controler.csv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]
2026-04-16 moved the converter, to the long side this time
    [BOM-MMS3_hat_stepper_controler.csv, Bus_switch.kicad_sch, ID_EEPROM.kicad_sch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]
2026-04-20 added more vias to XT60
    [BOM-MMS3_hat_stepper_controler.csv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]
2026-04-20 generated final gerber
    [BOM-MMS3_hat_stepper_controler.csv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]
2026-06-09 updated documentation
    [BOM-MMS3_hat_stepper_controler.csv, Bus_switch.kicad_sch, ID_EEPROM.kicad_sch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]
2026-10-06 added photo
    [BOM-MMS3_hat_stepper_controler.csv, Bus_switch.kicad_sch, ID_EEPROM.kicad_sch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]
